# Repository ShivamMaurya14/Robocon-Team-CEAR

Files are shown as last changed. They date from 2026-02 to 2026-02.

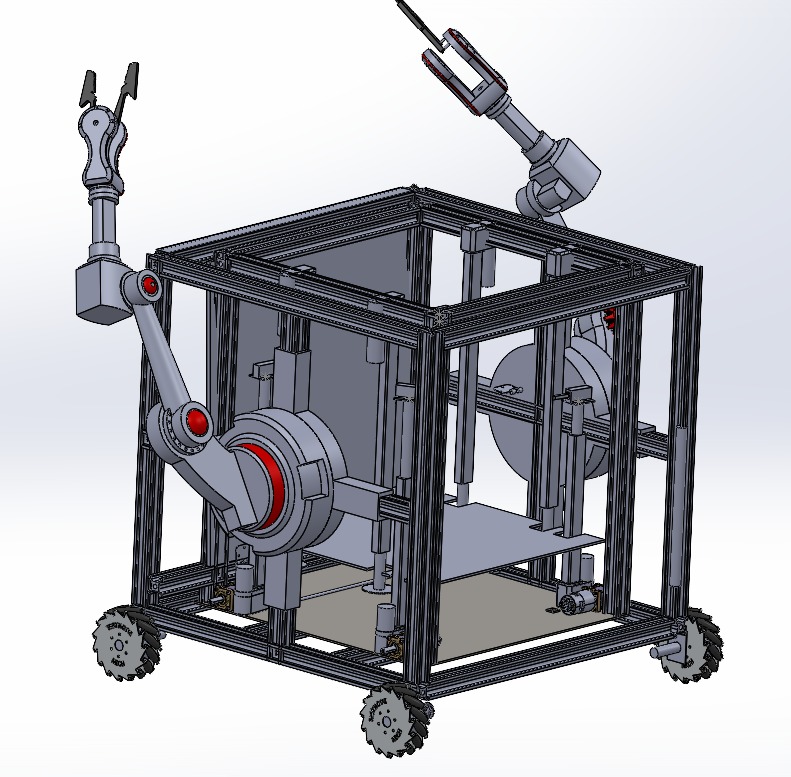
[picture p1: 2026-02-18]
R1_Views/compelte assembly.jpeg

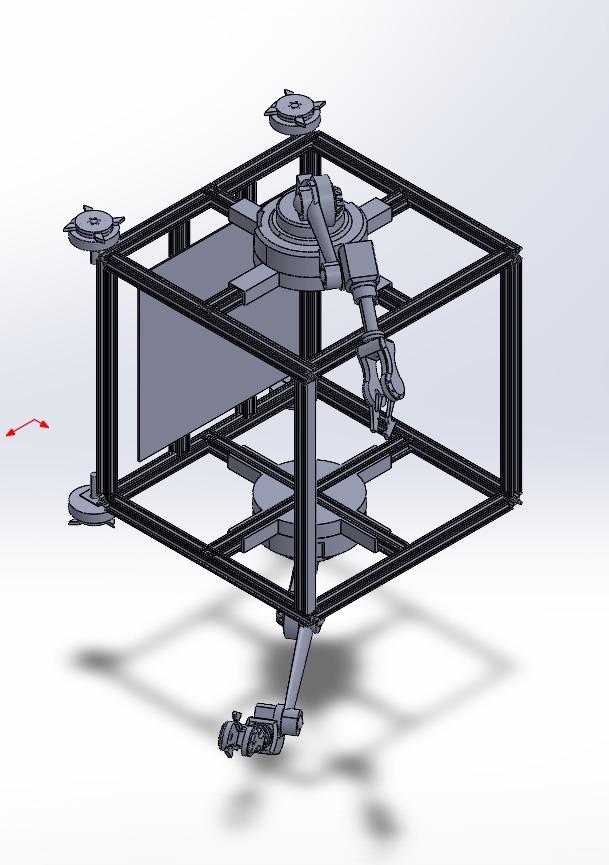
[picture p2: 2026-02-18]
R2_Views/isometric view R2.jpeg

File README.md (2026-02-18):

# 🤖 Team CEAR - Robocon 2026 Submission




Welcome to the official repository for **Team CEAR**'s Robocon 2026 submission. This repository contains the CAD models, technical documentation, design calculations, and the machine learning modules developed for the competition.

---

## 📂 Project Overview

### 🏛️ 1. CAD Designs & Visuals
Detailed 3D models and assembly views of our robots.
- **Root Files**: 
  - `Final.STEP`: The master assembly file for the robot design.
  - `Lifting-Mechanism .mp4`: Video demonstration of our custom lifting system.
- **R1_Views/**: High-resolution renders and technical views of Robot 1 (R1).
- **R2_Views/**: High-resolution renders and technical views of Robot 2 (R2).

### 🧠 2. Deep Learning: Box Detection
A specialized vision module to identify and classify game elements.
- **Location**: `FakeReal-box-detection/`
- **Features**: 
    - Convolutional Neural Network (CNN) built with TensorFlow/Keras.
    - Classifies boxes into "Real" and "Fake" categories.
    - Optimized for low-latency inference on edge devices.
    - Includes a full training pipeline and dataset management.

### 📊 3. Engineering & Calculations
Scientific grounding for our mechanical designs.
- **Location**: `Calculations/`
- **Contents**:
    - `Calculations.pdf`: Detailed stress analysis, torque requirements, and stability factors.
    - `linear actuators calculation.jpeg`: Selection criteria and stroke analysis for our actuator systems.

### 📄 4. Technical Documentation
- **`Stage I Document – CEAR.pdf`**: Our comprehensive project report detailing the strategy, mechanical design, electronics, and software architecture.

---

## 🛠️ Technological Stack

- **Mechanical Design**: SolidWorks / CAD Software (STEP, MP4 Exports)
- **Deep Learning**: Python, TensorFlow, Keras, NumPy
- **Documentation**: LaTeX/Markdown, Engineering Analysis

---

## 🚀 Key Features

- **Robust Vision System**: High-accuracy real/fake box classification for autonomous tasks.
- **Optimized Lifting Mechanism**: Custom-engineered system for efficient object handling.
- **Multi-Robot Coordination**: Designed for seamless integration between R1 and R2.

---

## 👥 Team CEAR

| Role | Details |
| :--- | :--- |
| **Team Name** | **CEAR** |
| **Project** | ABU Robocon 2026 |
| **Focus** | Robotics, AI Vision, Mechanical Excellence |

---

## 📜 License
This project is for Robocon 2026 submission purposes. All rights reserved by Team CEAR.

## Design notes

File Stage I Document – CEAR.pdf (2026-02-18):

# DD-Robocon 2026 – Stage I Submission

- Robot 1 (R1) is a manual robot.
- Robot 2 (R2) is a fully autonomous robot.

## Section 1: Solution Ideas

### Robot 1 (R1)

### 1. Overall Dimensions and Estimated Weight

The overall height, length and breath are 1000mm, 1000mm and 800mm respectively . The weight of R1 is 51.69kg after including all the components , material used, motors etc .

### 2. Drive Mechanism

We have used a four-wheel drive mechanism, in which wheels are mecanum wheels and we have used planetary gear box brushless motor with this a belt mechanism. We are using mecanum wheels because Move forward / backward, Move sideways (strafing), Move diagonally Rotate in place, Do all of these simultaneously .

### 3. Type of Actuators

We are using brushless motors with planetary gear box with 600rpm and 72 kg-cm torque , 12V DC 0.6A 7.5W Solenoid
Lock | , | Linear | Actuator | Stroke
Length300MM,7mm/S,1500N,12V,Linear Actuator Stroke Length 500MM 7mm/S 1000N 12V , Waveshare 30KG Serial Bus Servo , TowerPro MG996R Digital High Torque Servo Motor (360° Rotation)

### 4. Type of sensors integrated

MT6835 magnetic encoder module PWM/SPI brushless motor encoder with magnet , ultrasonic sensors

### Robot 2 (R2)

### 1. Overall Dimensions and Estimated Weight

The overall height, length and breath are 1000mm, 1000mm and 800mm respectively . The weight of R2 is 65 kg after including all the components , material used, motors etc .

2.Drive Mechanism

We have used a four-wheel drive mechanism, in which wheels reference is taken by the Synchro-Linkage mechanism, developed by Professor Eric Laithwaite .

### 2. Type of Actuators Used

We have used 4 brushless motors | with planetary gear
box . the reason | behind using brushless motors is it give
more torque than brushed one’s , 12V 150MM Stroke Length Linear Actuator 6000N 5mm/s .

### 3. Type of Sensors Integrated

MT6835 magnetic encoder module PWM/SPI brushless motor 21BIT encoder with magnet, Ultrasonic Distance sensor,Sensor,JetsonOrin,9-dof IMU1Mono,USBCameraD435,Dephth camera , RP lidarSE2 .

Section 2: Design Document, CAD Model and Mechanism Explanation

### 1. Description of Robot 1 (R1) with CAD view

### 1.1 Functional overview of R1

R1 is capable of : 1. Navigating the arena and R1 pathway with high stability and precision.

2.its gripper can hold staff with ease. 3.mecanum wheels helps R1 to operate in all direction easily .

4.R1 can pick up 1 kung-fu scroll at a time and it can store 2 scrolls inside its body .

5. R1 can carry assembled weapons inside its body and also take it out easily.
6. R1 is capable of lifting R2 to top most row of tic tac toe to help it place kung-fu scrolls or to push opponent teams scrolls .

7.R1 is capable of operating on a ground with inclination of 15 degrees.

### 1.2 Design philosophy

1.2.1 Material used: we have used Aluminium Extrusion because of following reasons Aluminium extrusions provide an excellent strength-to-weight ratio, reducing the overall mass of the robot while maintaining sufficient structural rigidity. This improves acceleration, manoeuvrability, and energy efficiency. The T-slot profile allows easy assembly, disassembly, and reconfiguration without welding , Dimensional Accuracy and Alignment , Corrosion Resistance, Flexibility for Mounting Components, Cost-Effective.

1.2.2 Robotic arm : The robotic arm used in R1 and R2 are same . both of them have 5 joints including 1 shoulder and a circular gripper is used .

1.2.3 Wheels : we have used mecanum wheels because of this R1 can Move forward / backward, Move sideways (strafing), Move diagonally Rotate in place, Do all of these simultaneously .

1.2.4 Belt mechanism : we have used belt mechanism because Belts naturally absorb vibrations and sudden load variations, protecting motors and gearboxes from impact loads during rapid acceleration, deceleration or collisions. belt mechanisms operate with minimal frictional losses , cost efficient and can work in confine spaces .

### 1.3 CAD views

### 1.3.1 Front view

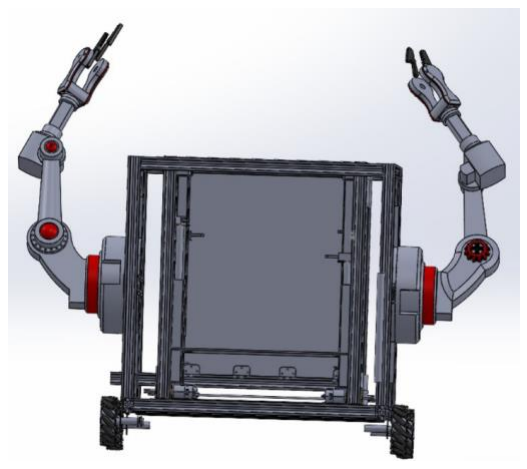
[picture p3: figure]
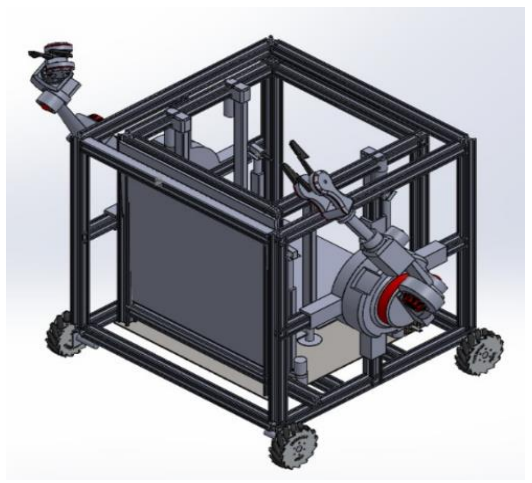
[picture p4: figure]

### 1.3.2 Back

### 1.3.3 Top

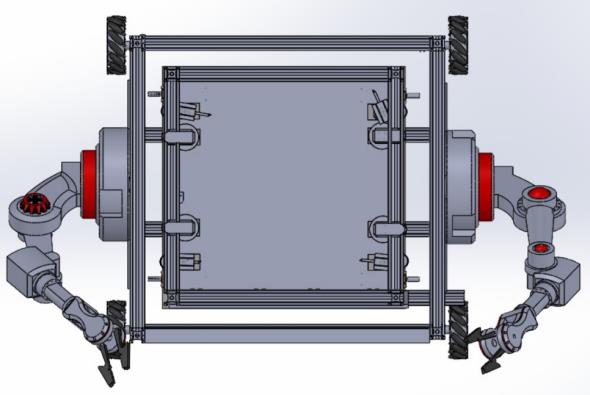
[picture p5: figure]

### 1.3.4 Bottom

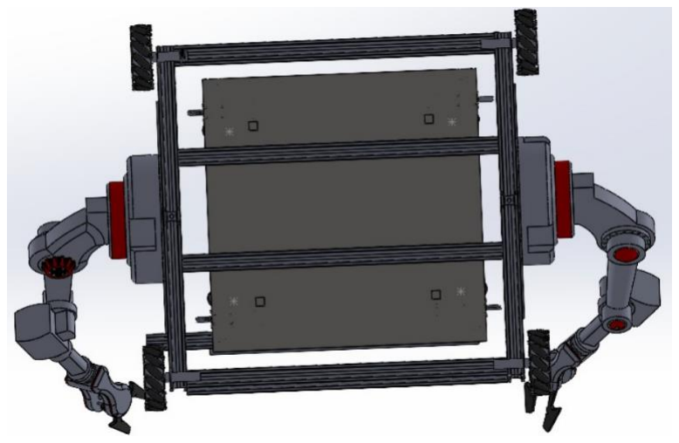
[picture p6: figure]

### 1.3.5 Isometric

### 1.3.6 Complete assembly

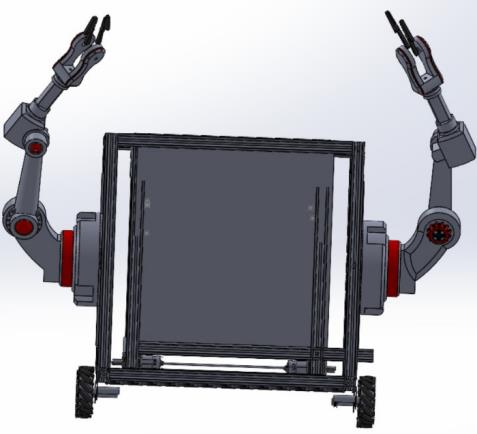
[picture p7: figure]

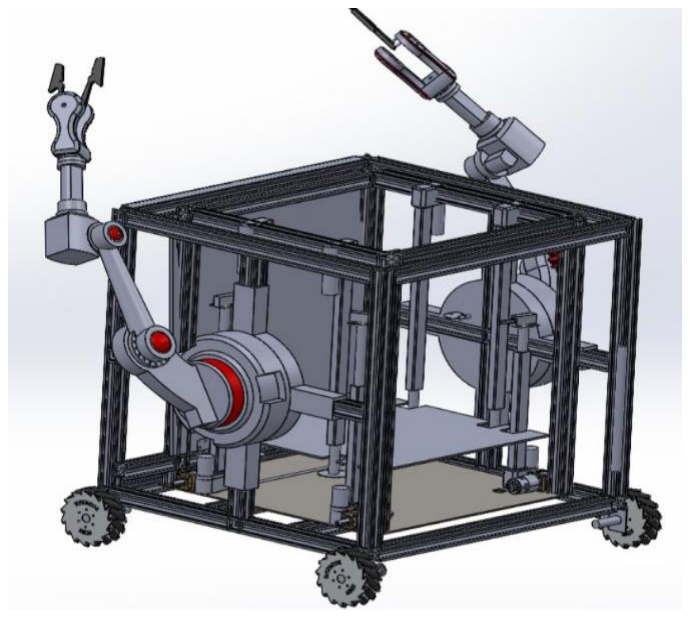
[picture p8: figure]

### 2. Description of Robot 2 (R2) with CAD Views

### 1.4 Functional overview of R2

1It R2 is cable of : 1. R2 is cable of operating on flat ground as well as on forest with ease

2. It can pick spearhead and hold them till assembly .
3. R2 can store 2 assembled weapons inside its body and also two kung-fu scrolls and take them out whenever required .
4. Its arm are capable of placing objects and pushing opponent teams scrolls from tic tac toe
5. R2 is capable of operating on a ground with inclination of 15 degrees.
6. R2 is capable of identification/differentiating between fake , R1 and R2 scrolls .

### 2.1 Design philosophy

2.2.1 Material used: 1material used: we have used Aluminium Extrusion because of following reasons Aluminium extrusions provide an excellent strength-toweight ratio, reducing the overall mass of the robot while maintaining sufficient structural rigidity. This improves acceleration, manoeuvrability, and energy efficiency. The T-slot profile allows easy assembly, disassembly, and reconfiguration without welding , Dimensional Accuracy and Alignment , Corrosion Resistance, Flexibility for Mounting Components, Cost-Effective.

2.2.2 Robotic arm : The robotic arm used in R1 and R2 are same . both of them have 5 joints including 1 shoulder and a circular gripper is used .

2.2.3 Wheels : we have used Synchro-Linkage wheels . How does wheels work : 1. When the machine is on flat ground, the whole triangle doesn't spin. Instead, the two bottom wheels just roll normally, like a regular cart. The third wheel sits on top, basically "resting."

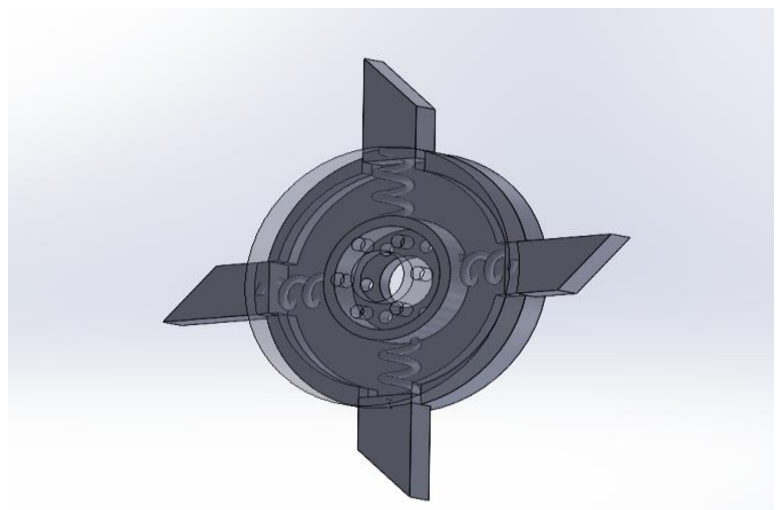
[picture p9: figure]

Figure1:synchro-linkage wheels

2. when wheels are about to touch stairs then front wheel hits the vertical face of a step, it can't roll forward anymore. The motor keeps pushing, and since the bottom wheel is stuck, the entire triangle assembly is forced to rotate.
3. On the flat surface, the outer wheel touches the ground first and the inner wheel which has triangle assembly is floating in air but the tringles coming out wheel hits the ground at certain angle and it goes in , after this these wheels works smooth on flat ground.

2.2.4 Belt mechanism: belt mechanism is same R1 2.2.5 Lifting Kungfu scrolls inside R2 :We are using 4 linear actuators and above a aluminium plate is keep and all this is keep in side a cuboidal box of metal sheets and Al extrusions and when needed the linear actuators lift the platform upwards and with that scrolls will come out in arena .

### 2.2 CAD views

### 3. Game Object Pick-and-Place Mechanism

(R1/R2)

### 3.1 Mechanism Description and Animation Views

We are using 2 robotic arms each bot . arm consist of 4 links , 1 Shoulder , 1 gripper .we are using circular gripper which are capable of picking up spearheads in a single arm . when R2 has picked 1 spear head then it holds the spearheads top towards is body , holding it in such a way that head touch’s body of R2 perpendicularly by this there is less chance of spear head slipping from gripper . meanwhile R1 pick up staff from staff rack and then a weapon is assembled and can be stored in R1/R2 . when R1/R2 are about to pick up kung-fu scrolls both arms rotate 90 degrees and the area of arm facing towards scroll has rubber grips on the surface . then both arms close down towards scroll just like a human is picking a big box with both hands , when scroll is picked by R1/R2 they can store scrolls inside there body . R1 can store 2 scrolls and R2 Can store 1 scroll . when R1/R2 are in arena , we have used a mechanism of linear actuators that can lift scrolls from their body .

### 3.2 Calculations / Justifications

1.Height of spear to be picked up = 50cm + 5.25cm = 55.25cm, Total = 60cm arm length , Lowest height of reach = 55.25 cm,Highest height of reach = 100 cm,

J2: 45.81 × 2 = 91 kg-cm (joint 2)

J3: 21.06 × 2 = 42 kg-cm(joint 3)

J4 - J6: 15 kg-cm (Wrist, joint 4 )

τ = 24.57 kg-cm (torque required for base of robotic arm )

these are the calculated results and the complete calculation’s word file has been attached to drive .

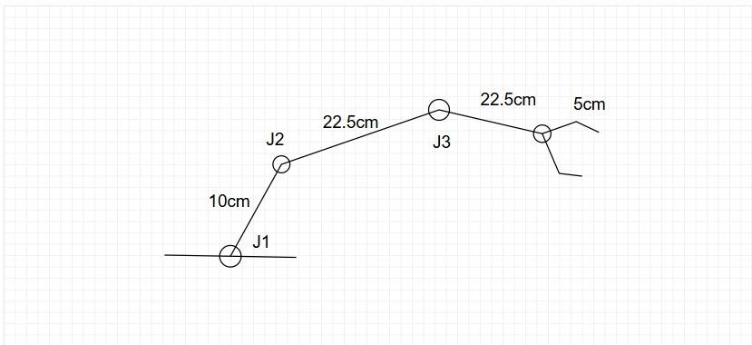
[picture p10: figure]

figure 3 : rough sketch of robotic arm used

### 3.3 CAD Model Views

4. Object Detection and Autonomous Navigation (R2)

### 4.1 System Description and Animation Views

4.1.1 Object Detection System: Multi-Camera Hardware Array: The vision system utilizes three standard RGB cameras mounted on the sides for a wide, peripheral field of view, alongside one front-facing depth camera. This configuration ensures comprehensive visual coverage of the arena with zero blind spots.

Edge Processing: The video streams from all four cameras are synchronized and fed into the central edge computing unit (NVIDIA Jetson Orin Nano). This setup handles the high bandwidth of multiple simultaneous video feeds while maintaining the real-time processing speeds necessary for competition.

4.1.2 Algorithm: Deep Learning Object Detection: A customtrained deep learning model is deployed to identify and classify the target boxes. The model processes the 2D RGB streams from the side cameras for rapid bounding box generation and object classification.

Sensor Fusion for 3D Localization: When a target box enters the front depth camera's field of view, the algorithm fuses the 2D bounding box detections with the spatial depth point cloud. This sensor fusion extracts the exact $x, y, z$ coordinates of the box relative to the robot, enabling precise mechanical alignment and interaction.

### 4.2 Autonomous Navigation

4.2.1 Navigation Algorithm and Software Environment: Odometry & Sensor Fusion (EKF): The robot calculates its continuous local position using a combination of Wheel Encoders and an IMU (Inertial Measurement Unit). The wheel encoders provide raw distance measurements, while the IMU provides high-frequency data on orientation (yaw) and acceleration. These inputs are mathematically fused using an Extended Kalman Filter (EKF) via the ROS 2 Jazzy robot_localization package to actively cancel out physical wheel slip and sensor drift. High-Fidelity Global Mapping: While the EKF handles local movement, the environment is perceived globally using the RPLIDAR S2E. Its Direct Time-of-Flight (DToF) technology and 32kHz sampling rate match real-time Lidar scans against the static arena map, correcting any accumulated odometry errors and maintaining exact global positioning.

Software Stack & Short-Goal Routing: Autonomous navigation is driven by the Nav2 stack, which processes the fused EKF odometry and Lidar data to update global and local costmaps in real-time. The algorithm is optimized using a sequential waypoint strategy where the global planner sends a series of "short goals" straight through the middle of the arena. This approach keeps the robot centralized, reduces computational overhead, and allows the local trajectory planner to react instantly to dynamic obstacles.

4.2.2 Simulation Animation Views: Vision System Validation: An animation view (simulated in Gazebo/RViz) illustrating the overlapping field-of-view cones of the four cameras, demonstrating the deep learning model successfully
recognizing | target | boxes | from | multiple | angles
simultaneously. | Dynamic Navigation & Sensor Fusion
Simulation: A top-down RViz animation displaying the local costmap generated by the RPLIDAR S2E. The view highlights the Nav2 behaviour tree in action, visualizing the robot smoothly executing its path from one short goal to the next. Crucially, the animation shows the raw encoder path diverging slightly, while the fused EKF odometry path remains perfectly aligned with the Lidar map, proving the stability of the navigation system.

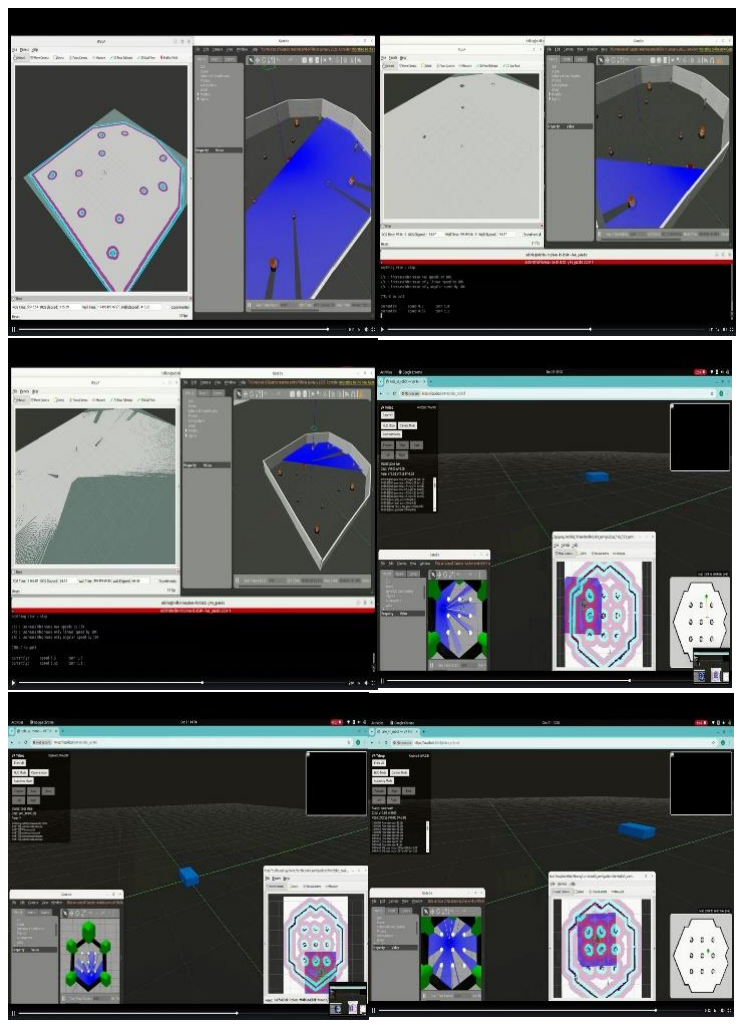
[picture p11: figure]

### 5. Lifting Mechanism

### 5.1 Mechanism Description and Animation Views:

We have used a total of 8 linear actuators in which 4 gives 350N , have 300mm stroke length and 4 give 1000N , have 500mm stroke length . 4 actuators [lets call it as A2(1000N)]are attached upside down and 4 actuators [lets call them A1(350N)] are attached normally (at 90 degrees)to the base plate . We have used another steel plate (P1) of 5mm thickness. We have attached four solenoid locks to each A1’s limit switches (refer to figure 12). A plate has been attached to A2’s limit switch of radius = 25mm. We have used four circular steel plates that are attached to the limit switch of A2, which are holding plate P1 above them. Originally, the P1 rests on the four circular plates. The A2 actuator starts pulling plate P1 upwards, when it reaches to the solenoid lock present on A1’s limit switch, then the solenoid lock will get activated and the rod inside comes out from lock, meanwhile the A2’s limit switch hits it max height that it can pull P1 plate. Now,
the P1 plate gets support from the rod which has came out of the A1’s solenoid lock. Now, the A1 actuators get activated and they will take the P1 plate to the maximum height (750mm from base plate).

### 5.2 Calculations / Justifications

No of actuators used : 8
350N , 300mm stroke length : 4 1000N , 500mm stroke length : 4 Total mass of R2 = 47 kg

### 5.3 CAD Model Views During Lifting

## 6. Weapon Assembly Mechanism

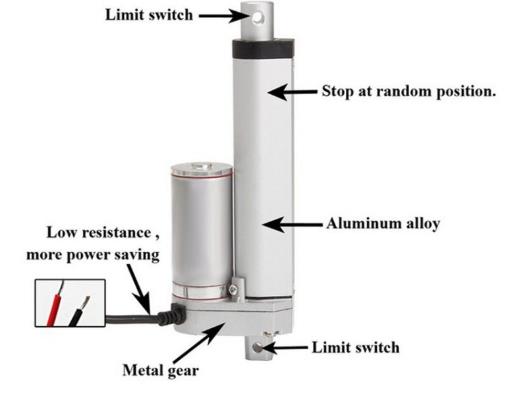
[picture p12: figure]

### 6.1 Mechanism Description

We have used circular grippers with a width wide enough to perfectly hold the Quick couplers of the spearhead and the staff as well.
The R2 bot will follow its designated path towards the spearhead rack and will pick up the desired spearhead with its gripper mechanism. The bot is programmed to itself rotate the spearhead and make it parallel towards its body, holding it firmly against its body so that it does not slips. Now the R1 bot will be moved towards the R2 bot manually to attach the staff to the spearhead to make a complete weapon. There is an LED constructed on the R1 manual bot which gets turned on as soon as the weapon is completed. This ensures that the R2’s gripper leaves the assembled weapon for its further usage.

### 6.2 Github Links:-

Contents:-

### 1. Views of R1 2. Views of R2 3. Lifting mechanism video 4. Calculation of linear actuator 5. Calculation of robotic arm 6. Object detection and navigation

https://github.com/ShivamMaurya14/Robocon-Team-CEAR

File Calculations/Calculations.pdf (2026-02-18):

# Arm

## Inverse Kinematics:

2 DOF, 3 DOF,

cos(θ) = (x² + y² - L₁ ² - L₂ ²) / (2L₁ L₂ )

### 6 DOF:

Equation: Wc = P – d₆ · Rz

Where:

- Wc: Wrist Centre
- P: Desired gripper position
- d₆ : Length of gripper
- Rz: Orientation described by rotation matrix

Dimensions of arm:

Let the arm be attached at 45 cm of height from base.

Spearhead Rack | Rod Rack

Height of spear to be picked up = 50cm + 5.25cm = 55.25cm

Link1 = 10cm, Link2 = 22.5cm, Link3 = 22.5cm, Link4 = 5cm,

Link5 = 5cm, Link6 = 5cm

Total = 60cm arm length

Reach Calculations:

- Lowest height of reach = 55.25 cm
- Highest height of reach = 100 cm

[ Considering 700³cm³ volume.]

Shoulder torque:

Equation: τ = (Larm × Wobj) + (Lcg× Warm)

Where:

- τ: Torque
- Larm: Length of arm
- Wobj: Weight of object
- Lcg: Length to Center of Gravity (CG)
- Warm: Weight of arm

Factor of Safety (FOS):

- Load capacity considered = 500 gram

Material:

- Arm made of aluminium / plastic

Weight Distribution (Total arm weight = 1 kg):

- Link 1 — 250 g
- Link 2 — 300 g
- Link 3 — 250 g
- Gripper — 200 g

J3 Calculation(Forearm, wrist & payload):

Assumption: Max moment is calculated, thinking arm is horizontal.

Equation: τJ3 = [m₃ × (l₃ / 2)] + (mw × l₃ ) + (mp × [l₃ + lw])

Substitution: τJ3 = [0.25 × 11.25] + (0.2 × 22.5) + (0.5 × 27.5)

Result: τJ3 = 21.06 kg-cm

J2 Calculation:

Equation: τJ2 = ML2 + ML3 + M W + M payload

Result: τ J2 = 45.81 kg-cm

Dynamic Torque:

Formula: τTotal = τstatic + variable

Calculations:

- J2: 45.81 × 2 = 91 kg-cm
- J3: 21.06 × 2 = 42 kg-cm
- J4 - J6: 15 kg-cm (Wrist)

For base,

Parameters:

- α = 5.23 rad/s² (approx)
- m = 1.5 kg
- max reach = 50 cm

Torque Calculations:

- τinertia = 0.653 N·m
- τfrictional = 0.15 N·m

Base Torque:

- τbase = 8.19 kg-cm × 3

Final Result: τ = 24.57 kg-cm

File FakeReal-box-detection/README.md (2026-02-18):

# 📦 Robocon Box Real/Fake Detection






<p align="center">
  <strong>A Deep Learning solution for the Robocon competition to classify boxes as "Real" or "Fake".</strong>
</p>

---

## 📖 Table of Contents
- [About the Project](#-about-the-project)
- [Key Features](#-key-features)
- [Project Structure](#-project-structure)
- [Getting Started](#-getting-started)
  - [Prerequisites](#prerequisites)
  - [Installation](#installation)
- [Usage](#-usage)
- [Model Architecture](#-model-architecture)
- [Results & Verification](#-results--verification)
- [Optimization Tips](#-optimization-tips)

---

## 🔍 About the Project

This repository hosts a robust **Convolutional Neural Network (CNN)** built with **TensorFlow** and **Keras** designed to distinguish between "Real" and "Fake" boxes. Originally developed for the **Robocon competition**, this model ensures high accuracy in object classification tasks essential for autonomous robotics.

The project includes a complete training pipeline within a Jupyter Notebook, covering data preprocessing, model training, evaluation, and real-time prediction verification.

---

## ✨ Key Features

- **Binary Classification**: Accurately classifies images into two categories: `Real` vs `Fake`.
- **Data Augmentation**: (Implicit in `image_dataset_from_directory` pipeline) Efficient data loading and caching for performance.
- **Visual Verification**: Includes a built-in verification tool to inspect model predictions against actual labels.
- **Portable**: Configured to run locally with relative paths, removing dependency on specific cloud environments (like Kaggle).

---

## 📂 Project Structure

```bash
Robocon_Box_detection_real_fake/
├── README.md              # Project documentation
├── realfake.ipynb         # Main Jupyter Notebook for training & inference
├── requirements.txt       # Python dependencies
├── .gitignore             # Git ignore rules
└── dataset/               # Image dataset directory
    ├── real/              # Training images for 'Real' boxes
    └── fake/              # Training images for 'Fake' boxes
```

---

## 🚀 Getting Started

Follow these steps to set up the project locally.

### Prerequisites

Ensure you have **Python 3.11+** installed. You will also need:
- TensorFlow
- NumPy
- Matplotlib
- Jupyter

### Installation

1.  **Clone the repository**
    ```bash
    git clone <repository_url>
    cd Robocon_Box_detection_real_fake
    ```

2.  **Create a virtual environment (Optional but recommended)**
    ```bash
    python -m venv venv
    source venv/bin/activate  # On Windows: venv\Scripts\activate
    ```

3.  **Install dependencies**
    ```bash
    pip install -r requirements.txt
    ```

---

## 💻 Usage

1.  **Prepare your dataset**:
    Ensure your images are organized in the `dataset/` folder as follows:
    - Put "Real" box images in `dataset/real/`
    - Put "Fake" box images in `dataset/fake/`

2.  **Launch the Notebook**:
    ```bash
    jupyter notebook realfake.ipynb
    ```

3.  **Train & Predict**:
    - Run all cells in the notebook.
    - The model will train for the specified epochs.
    - At the end, a **Verification Cell** will display random images with their actual and predicted labels for visual confirmation.

---

## 🧠 Model Architecture

The custom CNN architecture is optimized for speed and accuracy:

1.  **Input Layer**: Rescaling (Normalizes pixel values to [0, 1]).
2.  **Feature Extraction**:
    - 3x Convolutional Blocks (`Conv2D` + `MaxPooling2D`).
    - Uses `ReLU` activation for non-linearity.
3.  **Classification Head**:
    - `Flatten` layer.
    - `Dense` layer (128 units, ReLU).
    - `Dropout` (0.5) to prevent overfitting.
    - `Dense` Output layer (Sigmoid activation) for binary probability.

---

## 📊 Results & Verification

The model provides a confidence score for each prediction:

- **Result: REAL** (e.g., Confidence: 0.95)
- **Result: FAKE** (e.g., Confidence: 0.88)

You can instantly verify model performance using the integrated visualization tool in the notebook:

Verification Example  
*(The notebook will generate a real grid of images like this)*

---

## 💡 Optimization Tips

> [!TIP]
> **Capture Your Own Data**: For the best performance in the actual competition arena, avoid relying solely on downloaded datasets. **Train the model using images captured from the actual camera** you will use on the robot. This ensures the neural network adapts to your specific:
> - Camera lens distorion
> - Perspective and mounting height
> - Arena lighting conditions

---

## 📜 License

Distributed under the MIT License. See `LICENSE` for more information.

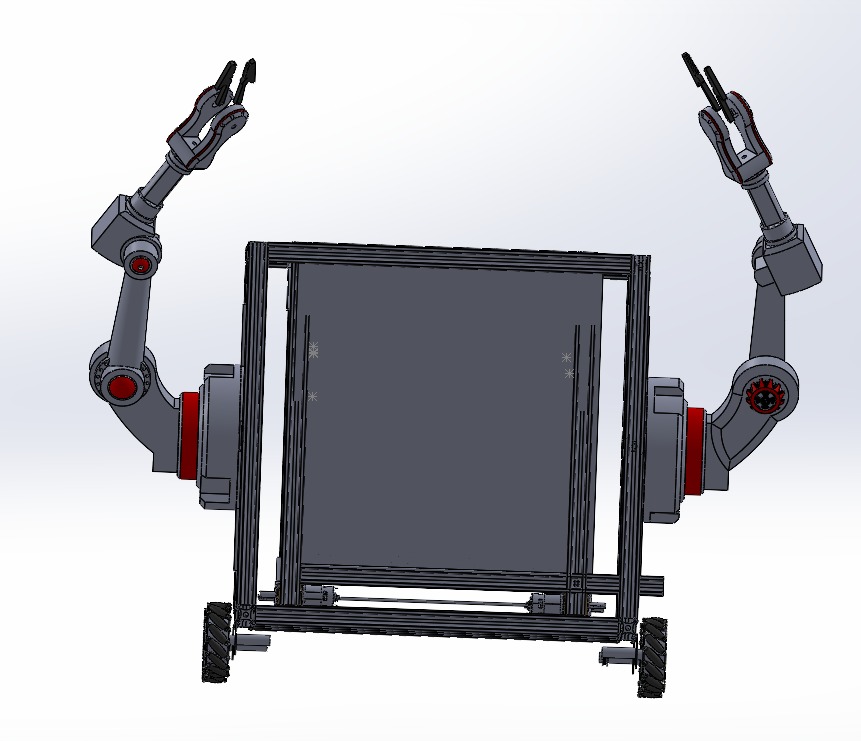
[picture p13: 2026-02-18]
R1_Views/front_view_R1.jpeg

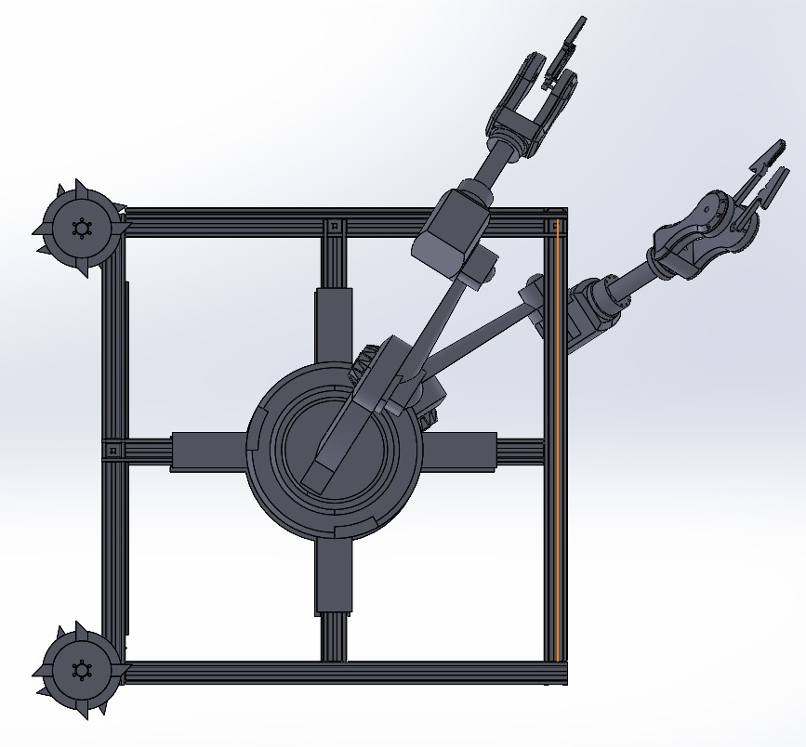
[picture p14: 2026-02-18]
R1_Views/side view r1 .jpeg

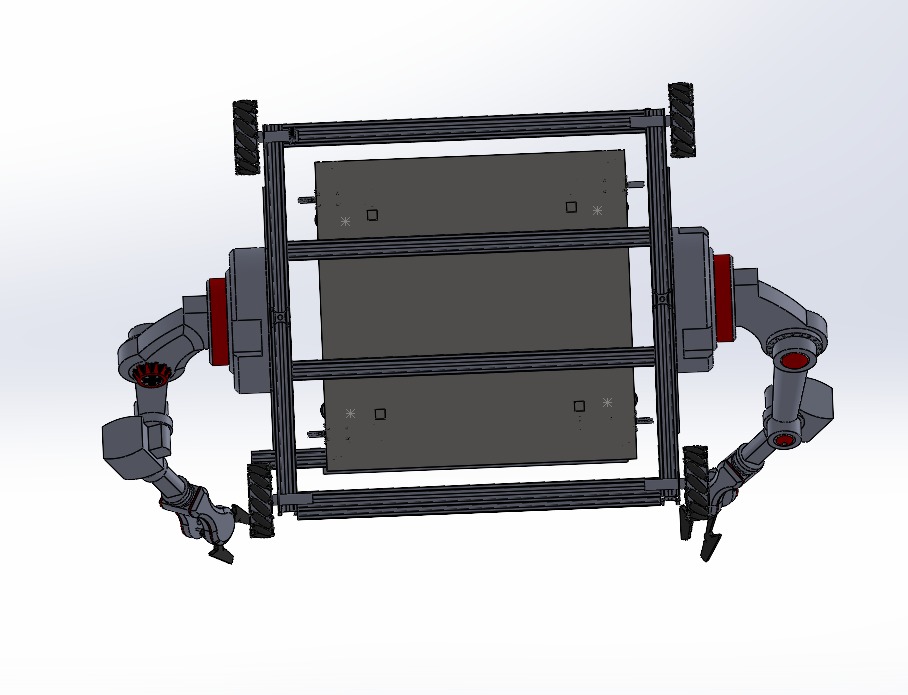
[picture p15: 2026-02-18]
R1_Views/bottom view R1.jpeg

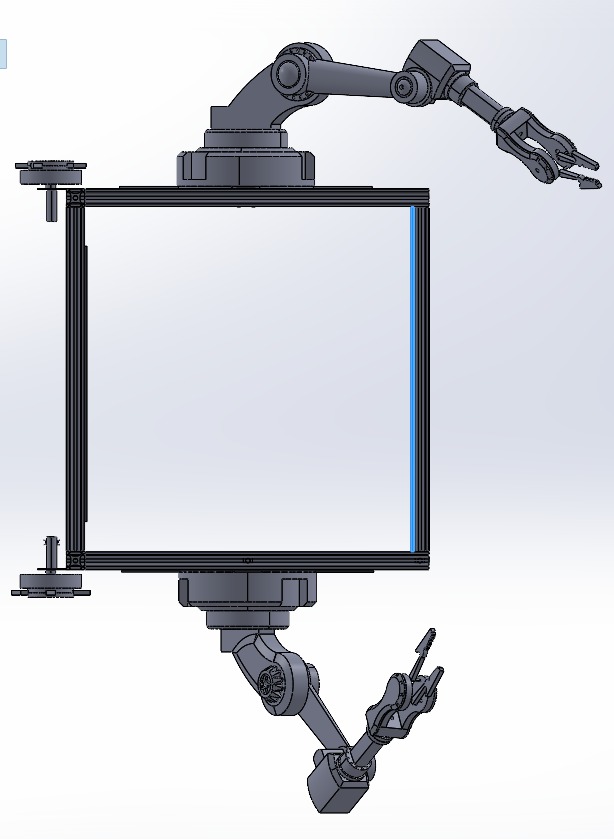
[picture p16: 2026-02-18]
R2_Views/front view R2.jpeg

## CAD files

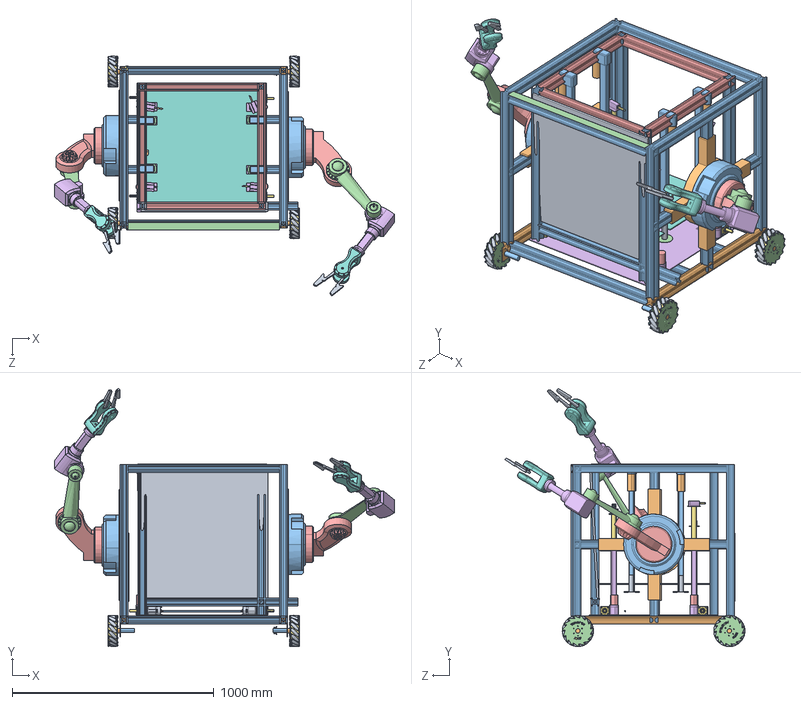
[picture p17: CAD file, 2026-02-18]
Final.STEP
1683.4 x 1278.7 x 1188.5 mm
hhhhhh x 21
right side.STEP x 4
right side-0.STEP x 4
supp.STEP x 4
bolt.STEP x 60
roller.STEP x 60
ttt
arrm x 2
circle x 2
dd x 2
ert x 4
gripper x 4
arm base x 2
base x 2
cover
219.igs x 4
Motor - RS-775.igs x 4
1.igs x 4
1.1.igs x 16
_61901_PART1_2.igs x 4
_61901_PART2_4.igs x 4
_61901_PART3_6.igs x 40
GEARBOX x 4
STROKE x 5
Part2plate
STROKE_500 x 4
GEAR2 x 4
Part3circlwe x 4
solenoid_lock_body x 4
solenoid_lock_shaft x 4
Ramp
hinge x 5
hinge rod x 2

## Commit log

2026-02-18 Add Robocon project files, including CAD models, calculations, and README
    [robocon complete final file.STEP]
2026-02-18 Move complete assembly image to R1_Views and finalize reorganization
2026-02-18 Rename CAD model to Final.STEP and clean up root directory
    [Final.STEP]

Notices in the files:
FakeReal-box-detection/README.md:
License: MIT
